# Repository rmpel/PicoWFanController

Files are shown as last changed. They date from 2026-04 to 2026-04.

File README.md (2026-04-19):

# PicoFanController

A small, quiet controller for a standard 4-wire PC fan, built around a
Raspberry Pi Pico W. Designed for dual duty: solder-fume extractor on the
bench, bedroom fan at night.

Control is by rotary encoder + push-button on the device itself, or over
WiFi via a built-in web UI and REST API. A 10-segment LED bar shows the
current speed at a glance.

## Features

- 25 kHz PWM drive, tachometer read-back, configurable PWM polarity
- Rotary encoder with short-press, double-click and press-and-hold gestures
- Predefined / boost / min speeds, configurable step size
- 10-LED bar graph for speed, also used as WiFi-status indicator at boot
- WiFi client with AP fallback and captive-portal-style setup page
- REST API + responsive web UI (main + advanced settings pages)
- Settings persisted in on-device json storage

## Repository layout

- [`Firmware/`](Firmware/README.md) — MicroPython firmware, web UI, install/deploy scripts
- [`HARDWARE.md`](HARDWARE.md) — schematic, PCB and bill of materials
- `PicoFanController.kicad_*` — KiCad 9 project files

## Getting started

1. Build or assemble the hardware — see [HARDWARE.md](HARDWARE.md).
2. Flash and configure the firmware — see [Firmware/README.md](Firmware/README.md).

## License

The repo is split into two licenses, both noncommercial, both requiring
attribution:

- **Firmware and web UI** (`Firmware/`) — [PolyForm Noncommercial 1.0.0](Firmware/LICENSE).
  A software-specific noncommercial license.
- **Hardware design** (schematic, PCB, `HARDWARE.md`) —
  [CC BY-NC-SA 4.0](LICENSE-HARDWARE). Attribution, noncommercial, share-alike.

In short: do what you like with it for personal, educational or hobby use,
credit the author, and share improvements under the same terms. For
commercial use or anything that would involve claiming ownership, contact
me first.

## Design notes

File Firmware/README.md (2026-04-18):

# PicoFanController — Firmware

MicroPython firmware for a Raspberry Pi Pico W that drives a 4-wire PC fan
(Foxconn PV123812DSPF01 / Dell, Intel 4-wire spec, 25 kHz PWM) with a
rotary-encoder + push-button UI and a small web interface.

Dual-use: fume extractor for soldering, and a quiet bedroom fan at night.

## Wiring

| Signal | GPIO | Notes |
|---|---|---|
| PWM out | 16 | 25 kHz to fan pin 4 (blue). Active HIGH default. |
| Tach in | 22 | Fan pin 3 (green). Pulled high to 3V3 via 10 kΩ. |
| Encoder CLK | 15 | Internal pull-up enabled in firmware. |
| Encoder DT | 14 | Internal pull-up enabled in firmware. |
| Encoder SW | 12 | Push-button. Internal pull-up enabled. |
| Status LED | — | On-board CYW43 LED ("LED"). |

Fan power: 12 V externally. Share GND with the Pico.

## First-time setup

```
./install.sh                       # installs mpremote and downloads MicroPython UF2
# flash the UF2 to the Pico W in BOOTSEL mode
./deploy.sh                        # copies firmware to device and resets
```

On first boot there are no WiFi credentials, so the device comes up in
**AP mode**. Connect to the open SSID `PicoFanController-XXXX` and browse to
`http://192.168.4.1`. Enter your WiFi credentials; the device reboots and joins
the network.

To force AP mode later, hold the encoder push-button while the Pico powers on.

## Status LED patterns

| Pattern | Meaning |
|---|---|
| 0.5 s on / 0.5 s off | Connecting to WiFi |
| SOS (· · · — — — · · ·) | WiFi connection failed |
| 5 s solid on | WiFi connected |
| short · short · long | AP (setup) mode |
| Single brief pulse | Encoder tick / button  |

## Control — physical

| Gesture | Action |
|---|---|
| Rotate encoder | ± *step* % per detent, snapped to a multiple of *step*  |
| Short press | Toggle between current speed ↔ predefined speed |
| Double click | Toggle "off" (= *min_speed*) ↔ previous speed |
| Press-and-hold (≥1 s) | Boost to *boost_speed* while held; restore on release |
| Hold at power-on | Force AP mode |

## Control — REST API

All endpoints return JSON. `GET` unless noted.

| Endpoint | Description |
|---|---|
| `/fancontrol/status` | Current speed %, RPM, settings, WiFi. |
| `/fancontrol/up` | Step up by *step* %, snapped. |
| `/fancontrol/down` | Step down by *step* %, snapped. |
| `/fancontrol/push` | Same as short-press button. |
| `/fancontrol/set-predefined?speed=N` | Persist predefined-speed value (0–100). |
| `/fancontrol/set-speed?speed=N` | Directly set fan speed (0–100). |
| `/fancontrol/settings` (GET) | Return all settings (no wifi password). |
| `/fancontrol/settings` (POST JSON) | Update settings. See keys below. |
| `/fancontrol/wifi` (POST JSON) | `{ssid, password}` — test and save. |

### Settings keys (stored in btree `/settings.db`)

| Key | Default  | Description |
|---|---|---|
| `current_speed` | 40 | Live duty %; written by firmware. |
| `previous_speed` | 40 | Last non-predefined speed (for toggles). |
| `predefined_speed` | 40 | Target of short-press / `/push`. |
| `boost_speed` | 100 | Target while hold-to-boost. |
| `min_speed` | 20 | "Off" level for double-click toggle. |
| `step` | 5 | % change per encoder tick / up / down. |
| `pwm_polarity` | `high` | `high` = Intel 4-wire spec; `low` to invert. |
| `tach_pulses_per_rev` | 2 | Standard PC fans = 2. |
| `hold_threshold_ms` | 1000 | Press-hold threshold for boost. |
| `device_name` | `PicoFanController` | Used in web UI + AP SSID. |
| `wifi_ssid`/`wifi_password` | —  | Set via `/fancontrol/wifi`. |

## Web UI

Open the Pico's IP in a browser. One page with:

- Large current-speed display and live RPM
- Up / down buttons and a number input for exact speed
- Predefined-speed, boost-speed, min-speed, step, hold threshold, tach PPR,
  PWM polarity, device name — each with ± buttons and number input
- "Save settings" button

## Safety notes

- `boot.py` pulls GPIO16 LOW before firmware starts → fan stays quiet on boot.
  (This is a comfort device, not a cooling-critical one.)
- If the fan misbehaves (e.g. runs full-blast and never slows), flip
  `pwm_polarity` to `low` in the web UI.

## Project layout

```
firmware/
├── boot.py                 # pulls PWM pin low before main runs
├── main.py                 # entry point
├── install.sh
├── deploy.sh
├── lib/
│   ├── config.py           # pin numbers, timings, defaults
│   ├── storage.py          # btree-backed settings
│   ├── fan_controller.py   # PWM + tach
│   ├── encoder.py          # quadrature decode + button FSM
│   ├── led_status.py       # non-blocking LED pattern player
│   ├── wifi_manager.py     # STA + AP mode
│   └── web_server.py       # HTTP server, core 1
└── web/
    ├── index.html
    ├── setup.html
    ├── script.js
    └── style.css
```

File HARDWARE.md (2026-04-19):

# PicoFanController — Hardware

KiCad 9 project for a small carrier board around a Raspberry Pi Pico W that
drives a 4-wire PC fan and a 10-segment LED bar.

## Files

- `PicoFanController.kicad_sch` — schematic
- `PicoFanController.kicad_pcb` — PCB layout
- `PicoFanController.kicad_pro` / `.kicad_prl` — KiCad project

Open `PicoFanController.kicad_pro` in KiCad 9 or later.

## Main components

- **Raspberry Pi Pico W** — MCU + WiFi, Pico2W should be compatible as well, maybe use a different MicroPython UF2? (untested)
- **IP2721_MAX12** — USB-C PD sink, negotiates 12 V from a PD-capable supply.
  This IC is somewhat hard to source; AliExpress has them but we all know how that goes. 
  CH224K is a relatively easy swap but will require different wiring. Is being researched for future version.
- **Si2302 N-channel MOSFET** — fan enable / hard cut-off - you can do without if you don't need a sof-power-off, short the Source and Drain on the pads.
- **HDSP-4832** — 10-segment LED bar for speed / status
- **Rotary encoder with push-button** — primary user input
- **USB-C receptacles** for power in (via PD), your choice to implement a flat or perpendicular port.
  A 2-pin screw terminal/solder connection is an alternative 12 V input
- Schottky diode, decoupling caps, pull-ups, current-limit resistors for
  the LED bar. Resistor values sub-optimal, software handles relative brightness to compensate

## Power

- 12 V in, either via USB-C PD (through the IP2721_MAX12) or directly on the
  screw terminal.
- 5 V is provided by a tiny buck converter, these are fragile as ... so I am planning my own buck circuit.
- Fan and Pico share GND (MosFet might be in between.

## Links

- [Tiny Buck Converter](https://nl.aliexpress.com/item/1005006366265832.html)
- [IP2721_MAX12](https://nl.aliexpress.com/item/1005009700524003.html)
- [Si2302](https://nl.aliexpress.com/item/1005011884423404.html)
- [LED Bar 10bit 4-color](https://nl.aliexpress.com/item/1005010480139258.html)
- [Rotary Encoder KY040 without PCB](https://nl.aliexpress.com/item/1005005983134515.html)

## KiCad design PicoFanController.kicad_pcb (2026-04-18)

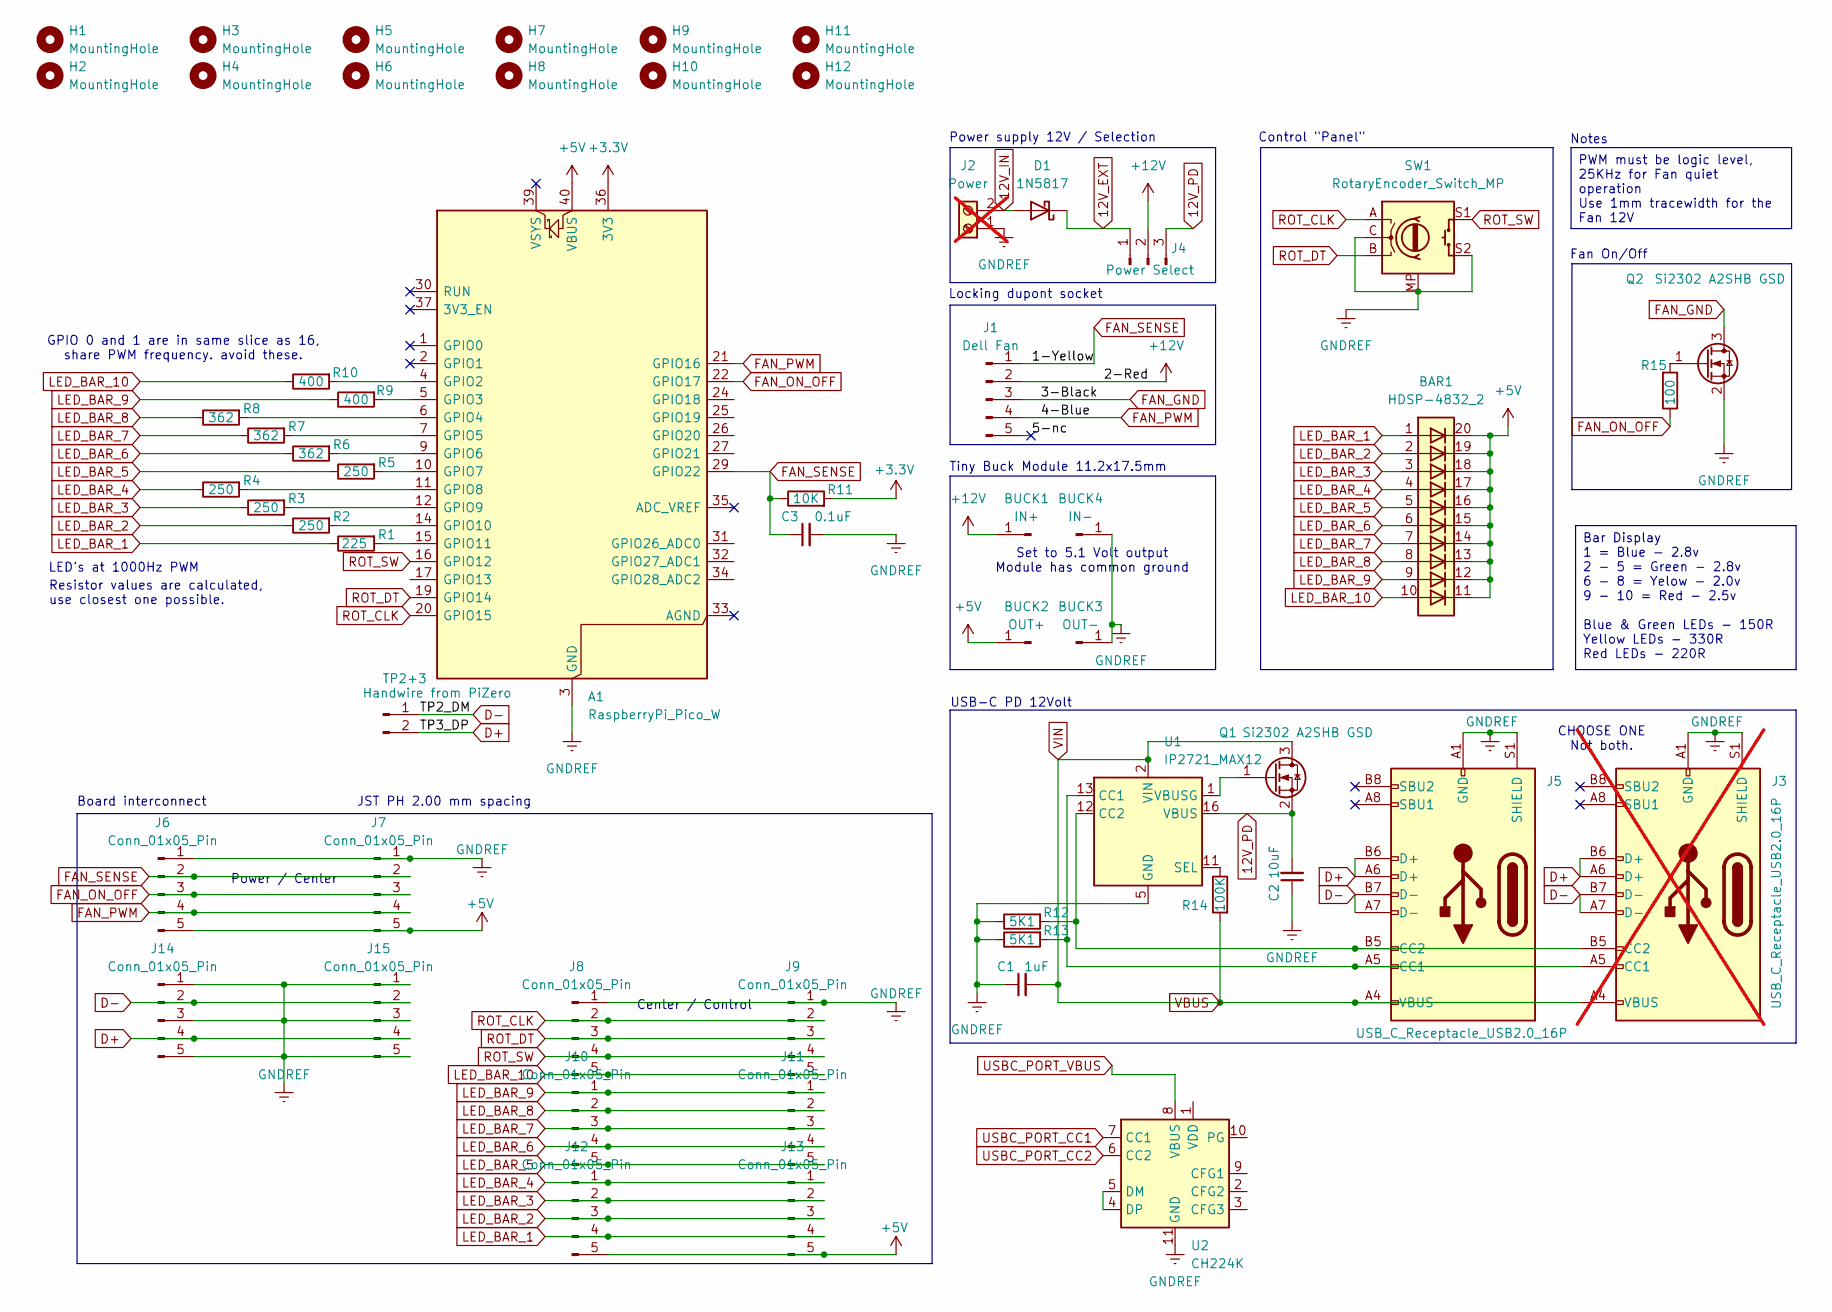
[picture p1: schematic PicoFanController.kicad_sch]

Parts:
A1: RaspberryPi_Pico_W; RaspberryPi_Pico_Common_THT
BAR1: HDSP-4832_2; HDSP-4832
BUCK1: IN+; SolderWire-0.75sqmm_1x01_D1.25mm_OD2.3mm
BUCK2: OUT+; SolderWire-0.75sqmm_1x01_D1.25mm_OD2.3mm
BUCK3: OUT-; SolderWire-0.75sqmm_1x01_D1.25mm_OD2.3mm
BUCK4: IN-; SolderWire-0.75sqmm_1x01_D1.25mm_OD2.3mm
C1: 1uF; C_0603_1608Metric_Pad1.08x0.95mm_HandSolder
C2: 10uF; C_0603_1608Metric_Pad1.08x0.95mm_HandSolder
C3: 0.1uF; C_0603_1608Metric_Pad1.08x0.95mm_HandSolder
D1: 1N5817; D_DO-15_P10.16mm_Horizontal
H1, H2, H3, H4, H5, H6, H7, H8, H9, H10, H11, H12: MountingHole; MountingHole_3.2mm_M3_DIN965
J1: Dell Fan; PinHeader_1x05_P2.54mm_Horizontal
J2: Power; TerminalBlock_Phoenix_MKDS-3-2-5.08_1x02_P5.08mm_Horizontal; not fitted
J3: USB_C_Receptacle_USB2.0_16P; USB_C_Receptacle_GCT_USB4105-xx-A_16P_TopMnt_Horizontal; not fitted
J4: Power Select; PinHeader_1x03_P2.54mm_Vertical
J5: USB_C_Receptacle_USB2.0_16P; USB_C_Receptacle_G-Switch_GT-USB-7051x
J6, J7, J8, J9, J10, J11, J12, J13, J14, J15: Conn_01x05_Pin; JST_PH_B5B-PH-K_1x05_P2.00mm_Vertical
Q1, Q2: Si2302 A2SHB GSD; SOT-23-3
R1: 225; R_0603_1608Metric_Pad0.98x0.95mm_HandSolder
R2, R3, R4, R5: 250; R_0603_1608Metric_Pad0.98x0.95mm_HandSolder
R6, R7, R8: 362; R_0603_1608Metric_Pad0.98x0.95mm_HandSolder
R9, R10: 400; R_0603_1608Metric_Pad0.98x0.95mm_HandSolder
R11: 10K; R_0603_1608Metric_Pad0.98x0.95mm_HandSolder
R12, R13: 5K1; R_0603_1608Metric_Pad0.98x0.95mm_HandSolder
R14: 100K; R_0603_1608Metric_Pad0.98x0.95mm_HandSolder
R15: 100; R_0603_1608Metric_Pad0.98x0.95mm_HandSolder
SW1: RotaryEncoder_Switch_MP; RotaryEncoder_Alps_EC11E-Switch_Vertical_H20mm
TP2+3: Handwire from PiZero; PinHeader_1x02_P2.54mm_Vertical
U1: IP2721_MAX12; TSSOP-16_4.4x5mm_P0.65mm
U2: CH224K; SSOP-10-1EP_3.9x4.9mm_P1mm_EP2.1x3.3mm

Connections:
12V_EXT: D1.1 (K), J4.1
12V_IN: D1.2 (A), J2.2
12V_PD: C2.2, J4.3, Q1.2 (S), U1.16 (VBUS)
+3.3V: A1.36 (3V3), R11.2
+5V: A1.40 (VBUS), BAR1.11 (K), BAR1.12 (K), BAR1.13 (K), BAR1.14 (K), BAR1.15 (K), BAR1.16 (K), BAR1.17 (K), BAR1.18 (K), BAR1.19 (K), BAR1.20 (K), BUCK2.1, J6.5, J7.5, J12.5, J13.5
+12V: BUCK1.1, J1.2, J4.2
/5-nc: J1.5
D+: J3.A6 (D+), J3.B6 (D+), J5.A6 (D+), J5.B6 (D+), J14.4, J15.4, TP2+3.2
D-: J3.A7 (D-), J3.B7 (D-), J5.A7 (D-), J5.B7 (D-), J14.2, J15.2, TP2+3.1
FAN_GND: J1.3, Q2.3 (D)
FAN_ON_OFF: A1.22 (GPIO17), J6.3, J7.3, R15.1
FAN_PWM: A1.21 (GPIO16), J1.4, J6.4, J7.4
FAN_SENSE: A1.29 (GPIO22), C3.1, J1.1, J6.2, J7.2, R11.1
GNDREF: A1.3 (GND), A1.8 (GND), A1.13 (GND), A1.18 (GND), A1.23 (GND), A1.28 (GND), A1.38 (GND), BUCK3.1, BUCK4.1, C1.1, C2.1, C3.2, J2.1, J3.A1 (GND), J3.A12 (GND), J3.B1 (GND), J3.B12 (GND), J3.S1 (SHIELD), J5.A1 (GND), J5.A12 (GND), J5.B1 (GND), J5.B12 (GND), J5.S1 (SHIELD), J6.1, J7.1, J8.1, J9.1, J14.1, J14.3, J14.5, J15.1, J15.3, J15.5, Q2.2 (S), R12.1, R13.1, SW1.C, SW1.MP, SW1.S2, U1.5 (GND), U2.11 (GND)
LED_BAR_1: BAR1.1 (A), J12.4, J13.4, R1.1
LED_BAR_2: BAR1.2 (A), J12.3, J13.3, R2.1
LED_BAR_3: BAR1.3 (A), J12.2, J13.2, R3.1
LED_BAR_4: BAR1.4 (A), J12.1, J13.1, R4.1
LED_BAR_5: BAR1.5 (A), J10.5, J11.5, R5.1
LED_BAR_6: BAR1.6 (A), J10.4, J11.4, R6.1
LED_BAR_7: BAR1.7 (A), J10.3, J11.3, R7.1
LED_BAR_8: BAR1.8 (A), J10.2, J11.2, R8.1
LED_BAR_9: BAR1.9 (A), J10.1, J11.1, R9.1
LED_BAR_10: BAR1.10 (A), J8.5, J9.5, R10.1
unnamed: A1.4 (GPIO2), R10.2
unnamed: A1.5 (GPIO3), R9.2
unnamed: A1.6 (GPIO4), R8.2
unnamed: A1.7 (GPIO5), R7.2
unnamed: A1.9 (GPIO6), R6.2
unnamed: A1.10 (GPIO7), R5.2
unnamed: A1.11 (GPIO8), R4.2
unnamed: A1.12 (GPIO9), R3.2
unnamed: A1.14 (GPIO10), R2.2
unnamed: A1.15 (GPIO11), R1.2
unnamed: J3.A5 (CC1), J5.A5 (CC1), R13.2, U1.13 (CC1)
unnamed: J3.B5 (CC2), J5.B5 (CC2), R12.2, U1.12 (CC2)
unnamed: Q1.1 (G), U1.1 (VBUSG)
unnamed: Q2.1 (G), R15.2
unnamed: R14.1, U1.11 (SEL)
unnamed: U2.4 (DP), U2.5 (DM)
ROT_CLK: A1.20 (GPIO15), J8.2, J9.2, SW1.A
ROT_DT: A1.19 (GPIO14), J8.3, J9.3, SW1.B
ROT_SW: A1.16 (GPIO12), J8.4, J9.4, SW1.S1
VBUS: C1.2, J3.A4 (VBUS), J3.A9 (VBUS), J3.B4 (VBUS), J3.B9 (VBUS), J5.A4 (VBUS), J5.A9 (VBUS), J5.B4 (VBUS), J5.B9 (VBUS), Q1.3 (D), R14.2, U1.2 (VIN)

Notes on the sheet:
Notes
Resistor values are calculated, use closest one possible.
Center / Control
Power / Center
USB-C PD 12Volt
JST PH 2.00 mm spacing
LED's at 1000Hz PWM
Set to 5.1 Volt output Module has common ground
Fan On/Off
CHOOSE ONE Not both.
Control "Panel"
GPIO 0 and 1 are in same slice as 16, share PWM frequency. avoid these.
Board interconnect
Tiny Buck Module 11.2x17.5mm
Power supply 12V / Selection
Locking dupont socket
PWM must be logic level, 25KHz for Fan quiet operation Use 1mm tracewidth for the Fan 12V
Bar Display 1 = Blue - 2.8v 2 - 5 = Green - 2.8v 6 - 8 = Yelow - 2.0v 9 - 10 = Red - 2.5v Blue & Green LEDs - 150R Yellow LEDs - 330R Red LEDs - 220R

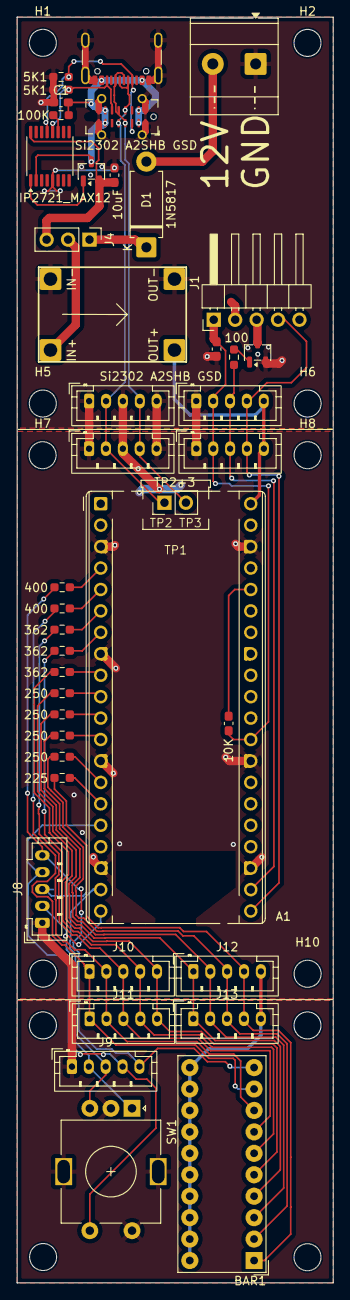
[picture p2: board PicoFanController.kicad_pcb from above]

Board: 2 copper layers, 37.5 x 150.0 mm, 57 parts (0 on the bottom side), 42 nets.

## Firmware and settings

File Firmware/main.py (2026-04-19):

import sys
import time
import _thread

sys.path.append("/lib")

from storage import Storage
from led_status import LedStatus
from led_bar import LedBar
from fan_controller import FanController
from encoder import RotaryEncoder, Button
from wifi_manager import WiFiManager
from web_server import WebServer


class App:
    def __init__(self):
        print("=" * 50)
        print("PicoFanController starting...")
        print("=" * 50)

        self.storage = Storage()
        self.led = LedStatus()
        self.fan = FanController(self.storage)
        self.led_bar = LedBar(self.storage, self.fan)
        self.led.set_mirror(self.led_bar.set_status)
        self.encoder = RotaryEncoder(lambda: self.storage.get("encoder_invert"))
        self.button = Button(lambda: self.storage.get("hold_threshold_ms"))
        self.wifi = WiFiManager(self.storage, self.led)
        self.web = WebServer(self.storage, self.wifi, self.fan)

        self._web_thread_started = False
        self._boost_active = False

    def start(self):
        force_ap = self.button.pressed_at_boot()
        if force_ap:
            print("Button held at boot -> forcing AP mode")

        if not force_ap and self.storage.has_wifi_config() and self.wifi.connect():
            pass
        else:
            self.wifi.start_ap_mode()

        if self.web.start():
            _thread.start_new_thread(self._web_loop, ())
            self._web_thread_started = True

        self.led.set_mirror(None)
        self.led_bar.release_status()
        self.led.set_pattern("off")

    def _web_loop(self):
        while True:
            try:
                self.web.handle_request()
            except Exception as e:
                print(f"web loop error: {e}")
            time.sleep_ms(2)

    def _handle_encoder(self):
        ticks = self.encoder.take_ticks()
        if ticks == 0:
            return
        for _ in range(abs(ticks)):
            if ticks > 0:
                self.fan.step_up()
            else:
                self.fan.step_down()
        self.led.flash_tick()

    def _handle_button(self):
        evt = self.button.update()
        if evt == Button.EVT_SHORT:
            self.fan.toggle_predefined()
            self.led.flash_tick()
        elif evt == Button.EVT_DOUBLE:
            self.fan.toggle_on_off()
            self.led.flash_tick()
        elif evt == Button.EVT_HOLD_START:
            self._boost_active = True
            self.fan.boost_start()
        elif evt == Button.EVT_HOLD_END:
            if self._boost_active:
                self.fan.boost_end()
                self._boost_active = False

    def run(self):
        print("Entering main loop")
        last_rpm_update = time.ticks_ms()
        while True:
            try:
                self._handle_encoder()
                self._handle_button()
                self.led.update()
                self.led_bar.update()

                now = time.ticks_ms()
                if time.ticks_diff(now, last_rpm_update) >= 500:
                    self.fan.update_rpm()
                    last_rpm_update = now

                time.sleep_ms(5)
            except Exception as e:
                print(f"Main loop error: {e}")
                sys.print_exception(e)
                time.sleep(1)


if __name__ == "__main__":
    app = App()
    try:
        app.start()
        app.run()
    except KeyboardInterrupt:
        print("Shutting down")
    except Exception as e:
        print(f"Fatal: {e}")
        sys.print_exception(e)

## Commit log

2026-04-18 Firmware working, schematic on it's way, but the IC is hard to get, refactor to use CH224K
    [PicoFanController.kicad_pcb, PicoFanController.kicad_sch]
2026-04-18 Postponed the refactor
    [PicoFanController.kicad_sch]
2026-04-19 first ledbar led now used for status during wifi for checking connection status, blinking is "connecting", SOS = failed to get wifi in 3 attempts, 5 second solid = WiFi connected. LED order is now co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
    [main.py]
2026-04-28 Add wireless file management
